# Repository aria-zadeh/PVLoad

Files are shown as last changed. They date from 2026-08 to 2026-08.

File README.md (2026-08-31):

# PVLoad

Automated I-V curve measurement for photovoltaic cells. A programmable resistive load steps through
769 load states while two bench multimeters record voltage and current at each one.

Hardware is a 2-layer PCB carrying two SPI digital potentiometers and three reed relays. Control is
MATLAB, over an Arduino Uno.

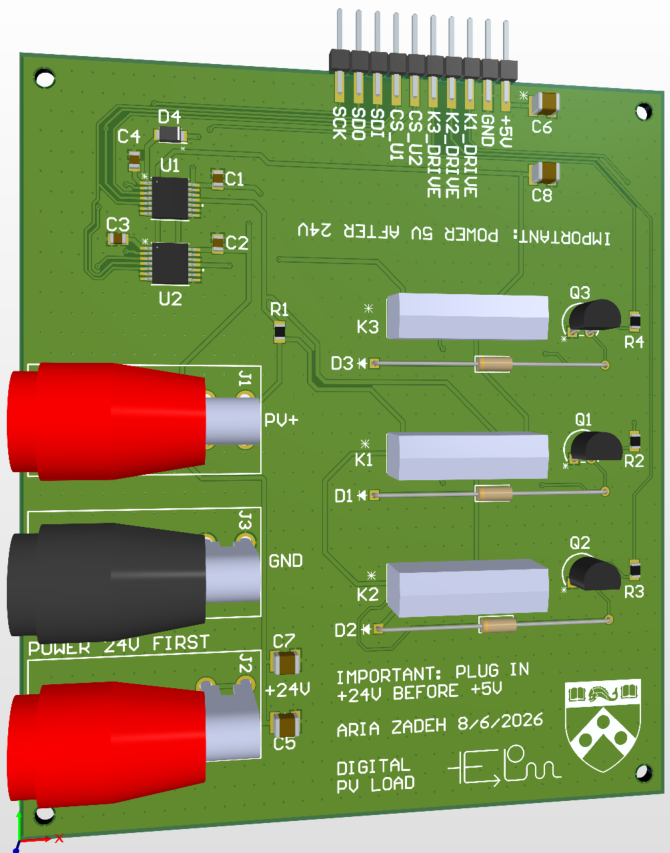
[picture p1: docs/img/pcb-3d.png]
PCB 3D render


## Overview

A cell's operating point depends on its load, so characterizing one means sweeping the load and
recording voltage and current at each step. This board replaces a manually adjusted resistor with
two MCP41HV51 digital potentiometers in series and three reed relays, giving 769 distinct load
states from 0.150 Ω to 470 kΩ under software control.

Relays reconfigure the topology to reach the ends of the curve, which the potentiometers cannot:

| Mode | Relay action | Region |
|---|---|---|
| `SHORT` | Bypass the whole load | Short-circuit current |
| `LOW` | Bypass the second potentiometer | ~155 Ω to 5.2 kΩ |
| `FULL` | Both potentiometers in series | ~310 Ω to 10.3 kΩ |
| `OPEN` | 470 kΩ in series | Open-circuit voltage |

`LOW` and `FULL` start from one and two wiper resistances respectively. The offset is not an integer
number of steps, so the two ladders interleave and resolve finer than the 19.6 Ω step size.

An I-V curve is only defined at a stated illumination, but the illumination is set by hand and the
software does not touch it. One run of the sweep is one curve at whatever light the bench is under;
a family of curves is several runs, told apart by `RUN_TAG`.

The board contains no measurement circuitry. Voltage and current come from two bench multimeters
addressed over VISA: a Keithley 196 and an Agilent 34401A.

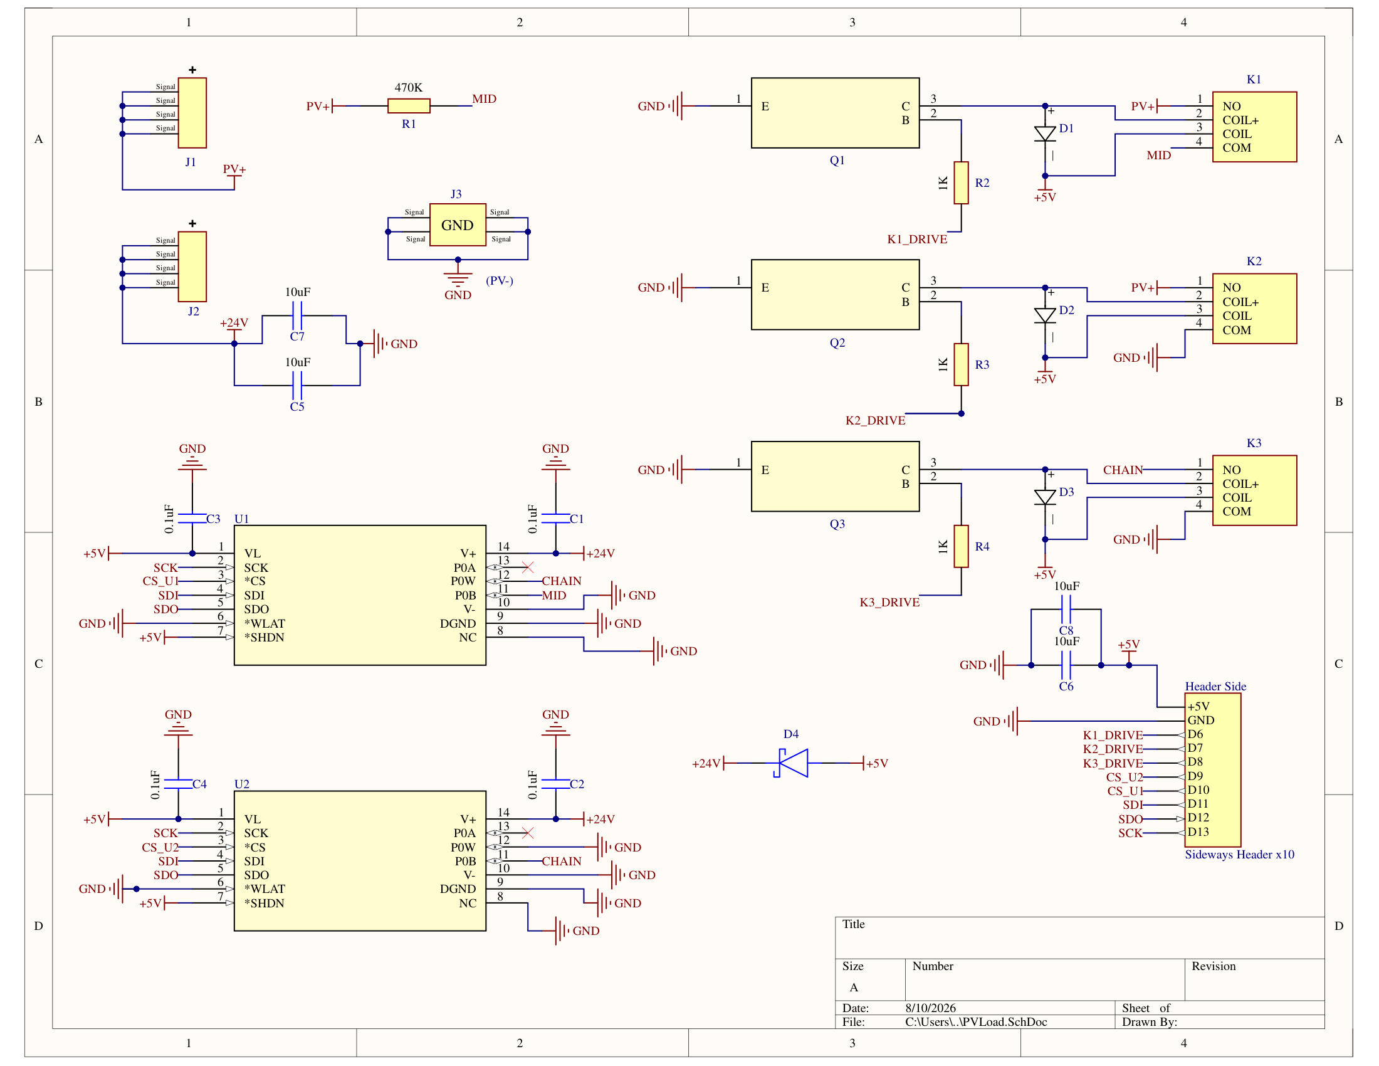
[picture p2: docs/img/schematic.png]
Schematic


## Specifications

| Parameter | Value |
|---|---|
| Load range, both potentiometers | ~310 Ω to 10.3 kΩ |
| Load range, one potentiometer bypassed | ~155 Ω to 5.2 kΩ |
| Step size | ~19.6 Ω |
| Load states per sweep | 769 |
| Short-circuit path | 0.150 Ω relay contact |
| Open-circuit path | 470 kΩ |
| Cell under test | ≤9 V open circuit, ≤16 mA short circuit |
| Illumination | Set by hand, not by this software |
| Control | SPI from an Arduino Uno, driven from MATLAB |
| Supplies | 24 V bench supply (analog), 5 V from the Arduino (logic) |
| Board | 2-layer, hand-assembled |

## Design notes

**Two potentiometers.** A single MCP41HV51-502 is 5 kΩ end to end. Two in series reach 10 kΩ and
produce the interleaved ladders described above.

**High-voltage potentiometer.** The MCP41HV51 separates its resistor-network supply from its logic
supply, so the network runs at 24 V while logic runs at 5 V. A cell reaching 9 V would clip a
part powered from the logic rail alone. This is why the board takes two supplies and why power
sequencing matters.

**Reed relays.** At 16 mA, contacts operate in dry-circuit conditions where silver-alloy power
contacts can develop surface films and read as intermittent opens. A sealed reed capsule avoids
this and holds contact resistance to 0.150 Ω, which sets the short-circuit endpoint. Coils draw
10 mA each and run from the Arduino's 5 V pin.

**Relay topology.** Every relay is wired in parallel with an element, never in series, since a
series relay could only break the loop. The open-circuit end is therefore a 470 kΩ resistor that K1
shorts out for the rest of the sweep, passing ~19 µA at 9 V.

**Coil drivers.** Each coil is switched by a 2N3904 low-side NPN through a 1 kΩ base resistor, with
a 1N4148 flyback diode across the coil. The relay has no internal diode.

**No on-board ADC.** An integrated converter would require calibration against a bench meter, so
the meters are used directly.

**Two meters.** Current is measured in series and voltage in parallel; one instrument cannot do
both simultaneously. Both are triggered before either reply is read, so their conversions overlap
and the readings describe the same instant. They need not be the same model, and on this bench they
are not: the voltmeter and the ammeter carry separate command profiles.

## Repository layout

```
docs/
  HARDWARE.md      Topology, pin map, SPI protocol, BOM
  DECISIONS.md     Design rationale and open questions
  BRINGUP.md       What has been measured on the assembled board
  METERS.md        The two meters, their dialects and status words
  TROUBLESHOOTING.md  Finding a fault with a handheld meter
  PVLoad_BenchCard.pdf   One-page printable bench reference
  benchcard.html   Source for the bench card
  img/             Schematic and PCB renders
hardware/
  altium/          Altium project, footprint and symbol libraries, STEP model
  gerbers/         Gerber X2 and NC drill files
  bom.pdf          Bill of materials
matlab/
  PVLoad_Main.m    Sweep controller and meter drivers
  test_arduino.m   Pin-by-pin bench test of the Arduino alone
data/
  sweep_data/      CSV output
figures/
  family_*.png     I-V and P-V across the laser drive levels, raw and fitted
```

[`docs/HARDWARE.md`](docs/HARDWARE.md) is the hardware reference: node-by-node topology, Arduino pin
map, SPI command format, initialization requirements, timing, and BOM with part selection reasoning.
[`docs/DECISIONS.md`](docs/DECISIONS.md) covers software design rationale and unresolved items.

## Requirements

| Component | Requires |
|---|---|
| Board | MATLAB R2019a+, MATLAB Support Package for Arduino Hardware, Arduino Uno, 24 V bench supply |
| Meters | A Keithley 196 and an Agilent 34401A, in either role. USB-GPIB adapter, Instrument Control Toolbox, vendor VISA runtime |
| Illumination | Whatever lights the cell. Set and recorded by hand |

No firmware to compile. The support package ships its own, and SPI transactions are issued from the
host over USB.

Instrument Control Toolbox does not include a VISA implementation. Install NI-VISA or Keysight IO
Libraries separately, matching the vendor to your GPIB adapter. Without one, `visadevlist` reports
`Unable to find VISA installations`; with one and no instruments attached it reports `Unable to
find any VISA resources`.

`DMM_V_MODEL`, `DMM_I_MODEL`, and `DMM_R_MODEL` select the instrument for each meter, from `"196"`
and `"34401A"`. The model is named per meter rather than once for the bench, so the voltmeter and
the ammeter can be different instruments, and here they are. One profile per model at the top of
Part 2 holds what differs: which command selects which function, what ranges exist, and how a
reading is decoded. Each meter carries its own profile from the moment it is opened.

The two speak different languages. On the 196 a command is a letter and a number, several travel in
one string, and nothing takes effect until an `X` arrives. The 34401A is SCPI, so its commands are
words, one per line, and a reading is a bare number with no prefix. Each profile carries a dialect
and the functions that talk to the bus branch on it, so both are in use at once during a sweep.

The 196 profile is read off Keithley 196-901-01 Rev D: functions from §3.9.2, ranges from table 3-9,
the setup string from table 3-8, the 24 ms conversion from table 3-16, and the reading tags from
figure 3-6. The 34401A profile is read off 34401-90004. Both have now been opened, identified and
configured on the bench; neither has been run against a cell. Either way the setup is followed by
the error query, so a command the meter does not know fails at configuration rather than producing a
wrong number. [docs/BRINGUP.md](docs/BRINGUP.md) records what the bench actually said, including the
three faults that took getting there.

The 196 has an IEEE-488 interface and nothing else, so it requires a USB-GPIB adapter. Match the
adapter to the installed VISA: NI-VISA drives National Instruments hardware, Keysight IO Libraries
drive Keysight hardware. The 34401A also has an RS-232 port, which VISA reaches as an `ASRL`
resource; the script sends `SYST:REM` on that transport only, because GPIB addressing does the same
job and the command is not valid there.

On Windows, Keysight VISA can fail inside MATLAB while working in every other program. MATLAB loads
the copy of `MSVCP140.dll` it ships in `bin\win64` in preference to the system copy, and if that copy
is older than the runtime Keysight IO Libraries was built against, the Keysight VISA library fails to
initialise. `instrhwinfo('visa')` then omits `keysight` and `visadevlist` finds nothing.
[docs/TROUBLESHOOTING.md](docs/TROUBLESHOOTING.md) has the diagnosis and the fix.

## Setup

Order matters. The cell is a supply, so it goes in last and comes out first — see
[Safety](#safety).

1. Connect the Arduino to the board through the 1x10 header.
2. Connect the bench supply to J2 (+24 V) and J3 (GND).
3. Connect the cell to J1 (PV+) and J3 (GND), with the ammeter in series on the PV+ lead, and
   keep it dark for now. Current goes into the ammeter's own terminal, `AMPS` on the 196 and the
   fused current terminal on the 34401A, never the volts terminal.
4. Connect the voltmeter across the cell terminals, upstream of the ammeter. Not across J1 and J3 —
   see [Measurement notes](#measurement-notes).
5. Power up 24 V first, then the Arduino.
6. Set `RUN`, the port and address settings, and `RUN_TAG` in Part 1 of `matlab/PVLoad_Main.m`,
   then start it.
7. Illuminate the cell once the script is running and the relays are in a defined state.

Shut down in reverse: darken the cell, then the Arduino's 5 V, then 24 V.

## Usage

`RUN` selects the mode. Each opens only the hardware it needs, so subsystems can be brought up
independently.

| `RUN` | Opens | Purpose |
|---|---|---|
| `"plan"` | nothing | Validate configuration, print time estimate |
| `"board"` | Arduino | Safe state, potentiometer self-test, walk a spread of load states |
| `"ramp"` | Arduino | Climb the resistance range slowly enough to follow on a handheld meter |
| `"wiper"` | Arduino | Park at the state pairs whose difference is one wiper resistance |
| `"verify"` | Arduino | Seven holds that exercise every part of a freshly built board |
| `"ohms"` | Arduino, one meter | Measure every state in the sweep on ohms, write a CSV and save a plot |
| `"meters"` | both sweep meters | Identify, configure, take ten readings |
| `"sweep"` | Arduino, both meters | Full experiment, written to CSV |

`"sweep"` enters the safe state, self-tests both potentiometers over SPI, sizes the ammeter range
once, then steps through every load state:

```
[  42/ 769] LOW    U1= 41  U2=  0  ~   1004.1 ohm   V=  6.21180  I=   9.8340 mA
```

Press Ctrl-C once and wait ~3 seconds to abort. The cleanup handler returns the board to `OPEN` and
closes the meters. Darkening the cell is yours, the same as lighting it was.

`SELF_TEST = false` skips potentiometer readback, allowing the control flow to run on a bare Arduino
with the board disconnected.

## Configuration

`PVLoad_Main.m` is split into two parts. Part 1 holds the settings intended to be changed. Part 2
describes the pin map and the meter command sets, and changes only with the hardware.

| Setting | Description |
|---|---|
| `RUN` | Mode, per the table above |
| `SERIAL_PORT` | Arduino COM port; enumerate with `serialportlist("available")` |
| `DMM_V_ADDRESS`, `DMM_I_ADDRESS` | VISA resource strings; enumerate with `visadevlist` |
| `DMM_R_ADDRESS` | VISA resource string of the single meter `"ohms"` uses; that mode ignores `DMM_ENABLED` |
| `DMM_V_MODEL`, `DMM_I_MODEL`, `DMM_R_MODEL` | `"196"` or `"34401A"` per meter; selects the command profile and range lists. They need not match |
| `DMM_V_RANGE`, `DMM_I_RANGE`, `DMM_R_RANGE` | Fixed meter ranges, or 0 to size from the probe and then follow the reading |
| `CODE_STEP` | States visited, `767/step + 2`. 1 gives 769 and about six minutes, 16 gives 50 and about half a minute |
| `POINT_BUDGET` | The most one state may cost end to end. The hold is what is left after the conversion and the board |
| `DMM_ENABLED` | Whether both sweep meters are attached |
| `ISC_FULL`, `VOC_FULL` | Zero, the normal setting, means the sweep measures the cell itself before it starts and sizes the meters from that. A number pins the range instead, for a family of runs at different light |
| `RAMP_STEPS`, `RAMP_DWELL` | States visited by `"ramp"` and how long each state is held |
| `DMM_NPLC`, `DMM_LINE_HZ` | Integration time in power line cycles, and the mains frequency that turns it into seconds. 34401A only |
| `WIPER_CODES` | Codes `"wiper"` compares at |
| `OHMS_SETTLE` | Per-state hold in `"ohms"` before the reading is triggered |
| `SETTLE_TIME` | Per-state hold when no meters are attached |
| `WRITE_CSV`, `OUT_DIR`, `RUN_TAG` | Output. `RUN_TAG` is the only record of the illumination |

The two meters are not the same speed. The 196 has a resolution setting rather than an integration
time; its profile asks for 5.5 digits, which is one line cycle of integration and 24 ms from trigger
to reading-ready. The 34401A integrates for `DMM_NPLC` power line cycles, doubled when
`DMM_ZERO_CORRECT` is set because autozero takes a zero reading between measurements: about 390 ms
at the default 10 NPLC. Both are triggered before either reply is read, so a point costs the slower
of the two rather than their sum, and a 769-state sweep takes about six minutes. `RUN = "plan"`
prints the estimate for a given configuration.

### Checking the load with a handheld meter

`RUN = "ramp"` needs no cell and no bench meters. Bring up 24 V, then the Arduino,
clip a handheld meter across J1 and J3 in ohms, and run it. The board climbs from the `SHORT` relay
contact to the 470 kΩ `OPEN` path in `RAMP_STEPS` stages, holding each for `RAMP_DWELL` seconds so
an autoranging meter has time to settle.

The printed ohms come from the resistance model, not from the board. `R_WIPER` is a worst-case
bound rather than a measurement and `R_AB` is ±20%, so expect the meter to disagree.

`RUN = "wiper"` turns that disagreement into a number. Probe, jack and trace resistance is common
to every reading a handheld takes, so it is removed by subtracting two readings rather than by
trusting either one. Writing `s` for the ladder step, and noting that a `FULL` state at code sum
`n` puts `U1` at `n` and `U2` at zero:

```
SHORT   = K2
LOW(n)  = K1 + Rw1 + n·s + K3
FULL(n) = K1 + Rw1 + n·s + Rw2
```

`LOW(0) − SHORT` is `Rw1` and `FULL(n) − LOW(n)` is `Rw2`, each to within a 0.150 Ω reed contact.
Neither difference contains the leads, the jacks or K1. `Rw2` is a switch rather than a resistor,
so the same value should come back at every code in `WIPER_CODES`; one that tracks the code is
`R_AB` being wrong instead.

### Measuring the load with one meter

`RUN = "ohms"` is `"ramp"` with the copying down done by an instrument. It needs the Arduino and a
single meter on ohms across J1 and J3, with no cell and no second meter, so
`DMM_ENABLED` stays out of it and `DMM_R_ADDRESS` says which meter to open. Bring up 24 V before the
Arduino as usual: the potentiometer resistor networks run from that rail, and a board without it
reads as series resistance rather than as a ladder. Every one of the 769 states is visited once,
held for `OHMS_SETTLE`, and read.

The output is two files under `OUT_DIR`, sharing one timestamp: `pvload_<stamp>_ohms.csv` with a row
per state, and `pvload_<stamp>_ohms.png` plotting measured resistance against the model on log axes,
with the ratio of the two below it. A ratio of 1 is agreement.

Neither meter reaches the bottom of the sweep: the lowest ohms range is 300 Ω on the 196 and 100 Ω
on the 34401A, against a 0.150 Ω `SHORT` contact. `DMM_R_RANGE` therefore defaults to the instrument's own
autorange, and the low end is measured on the coarsest part of the most sensitive range. Points the
meter returns as zero or negative stay in the CSV and are counted on the console rather than plotted.
A reading carries the leads, the jacks and the traces exactly as a handheld does, so a constant few
ohms across every point is the wiring.

`R_WIPER` is 155 Ω per device, measured with `RUN = "verify"` on the assembled board and recorded
in [docs/BRINGUP.md](docs/BRINGUP.md). `CELL_SETTLE` is still a placeholder at zero, and it is the
settle-model term that matters most at high resistance. Measure and replace it.

## Output

`"sweep"` writes one timestamped CSV to `data/sweep_data/`, `pvload_<stamp>.csv`, with a row per
point: `timestamp`, `state_index`, `mode`, `u1_code`, `u2_code`, `r_nominal_ohm`, `voltage_v`,
`current_a`, `resistance_ohm`, `power_w`, `settle_s`.

`resistance_ohm` and `power_w` are derived from measured voltage and current. `r_nominal_ohm` is the
model estimate used to order the sweep and is not a measurement.

Nothing in the file records the illumination, because nothing in the script knows it. Set `RUN_TAG`
before the run; it goes into the file name and is what tells two runs at different light apart.

Rows are appended in blocks of 64 states, so an aborted run retains everything up to the last block
boundary. The timestamp is what stops a second run overwriting the first.

## Measurement notes

Neither instrument here is an electrometer. Both are 6.5 digit DMMs, and both of the arguments
below follow from that.

**Burden voltage.** Connect the voltmeter across the cell terminals, upstream of the ammeter, rather
than across J1 and J3. A voltmeter downstream of the ammeter reads low by the ammeter's burden drop,
and both of these meters read current across a shunt. On the 34401A the shunt is 5 Ω for the 10 mA
and 100 mA ranges, so a 16 mA cell on the 100 mA range costs 80 mV. That is large enough to change
the shape of the curve, not just its offset.

**Input impedance, and which meter to put on volts.** Both meters present megohms rather than
hundreds of teraohms, and against the 470 kΩ `OPEN` path that is a divider rather than a rounding
error: a 10 MΩ input reads Voc about 4.5% low.

The 34401A can be told otherwise. `INP:IMP:AUTO ON` raises its input past 10 GΩ, and the script
sends that command to whichever meter is the voltmeter. It only applies on the 100 mV, 1 V, and
10 V ranges, so a `VOC_FULL` that pushes the meter onto 100 V puts the divider back. The setting is
volatile and `CONFigure` clears it, which is why it is sent after the range on every configuration.

The 196 has no equivalent command. Its 30 V range, where a 9 V Voc lands, is 10 MΩ.

So put the **34401A on volts and the 196 on amps**. On current the two are close enough not to
matter; on voltage they are not. Nothing in the configuration warns about this, because nothing in
the configuration knows the source impedance of the cell.

**Current range.** A ~16 mA cell lands on the 196's 30 mA range and the 34401A's 100 mA range. The
range starts where the probe put it and then follows the reading, widening at 90 % of range or on
an overflow and narrowing under 8 %. A cell whose illumination drifts costs a range change rather
than the run. An `ISC_FULL` above the meter's top range is
refused at configuration time; one far below its lowest range is a warning, not an error.

**Isc.** The burden drop and the 0.150 Ω relay contact put the `SHORT` state at millivolts rather
than at 0 V. Voltage is measured at every point, so `SHORT` is the lowest-voltage point on the curve
rather than a point defined to be at zero. Isc is obtained by extrapolating to V = 0.

Instrument commands are collected in one profile per model in Part 2, selected per meter by
`DMM_V_MODEL`, `DMM_I_MODEL`, and `DMM_R_MODEL`. Two dialects are supported: Keithley's own
device-dependent command language, which does not port beyond that family, and SCPI.

## Safety

- 24 V must come up before 5 V, and 5 V must come down first. D4, a Schottky from +5 V to +24 V,
  clamps the rails if the sequence is wrong, but it does not make the board usable on 5 V alone:
  V+ then sits about 0.35 V below VL, far below the 10 V the resistor network needs. There is no
  overvoltage protection, and a bench supply connected backwards gives the Arduino's 5 V rail a
  current path through D4.
- **The cell is a supply, so it belongs in the sequence too: illuminate it last, darken it first.**
  PV+ reaches U1's P0B, through R1 normally and directly through K1's contacts once K1 is energized.
  The datasheet limits those pins to `V+ + 0.3 V`, so a lit cell on an unpowered board is roughly
  8.7 V past absolute maximum. With all relays released, R1 holds that to ~19 µA against a ±20 mA
  clamp rating, which is harmless. But if 24 V drops out while 5 V is still up and K1 is closed, R1
  is shorted and the cell's full ~16 mA goes into the clamp — 80% of the absolute maximum, and the
  case that destroys a chip. D4 does not protect this path; it sits between the rails. Blocking the
  light is equivalent to unplugging and easier on the jacks. Since the illumination is set by hand,
  this sequence is entirely yours to get right; nothing in the software can enforce it.
  `docs/HARDWARE.md` §7 has the ratings.
- Never close the short-circuit relay during an open-circuit reading. A 0.150 Ω contact in parallel
  with 470 kΩ collapses the reading to roughly 0 V.
- Do not calculate resistance from the wiper code. The potentiometers carry ±20% tolerance and
  wiper resistance at a 24 V span is not characterized. Work from measured voltage and current.

## Testing without the board

`matlab/test_arduino.m` verifies that every pin the design uses can drive and read, using only the
Arduino, a USB cable, a multimeter, and jumper wires. It includes an SPI loopback test.

## License

MIT. See [LICENSE](LICENSE).

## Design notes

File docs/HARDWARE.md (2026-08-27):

# PVLoad-R1 Hardware Specification

Digitally controlled programmable resistive load for photovoltaic cell I-V characterization.
This document is the complete reference needed to write control software for the board.
It describes what the hardware is and how to drive it. It does not cover PCB layout or fabrication.

---

## 1. What the board does

Two high-voltage SPI digital potentiometers are wired in series to form a two-terminal load.
Three reed relays bypass parts of that load to extend the reachable range past what the
potentiometers alone can produce. An Arduino Uno sets the wiper codes and relay states.

The board is placed in a single series loop with a PV cell. Sweeping the load and recording
voltage and current at each step traces the cell's I-V curve, from which the maximum power
point, fill factor, and matched load resistance are computed.

**The board contains no measurement circuitry.** Voltage and current are read by two external bench
multimeters addressed over VISA, a Keithley 196 and an Agilent 34401A. Software sets the load state,
reads both meters at each point, and writes the results to CSV.

### Design targets

| Parameter | Value |
|---|---|
| Device under test | PV cell, up to ~9 V open circuit, ~16 mA short circuit |
| Load range, both pots in circuit | ~400 Ω to 10 kΩ |
| Load range, DigiPot 2 bypassed | ~155 Ω to 5.2 kΩ |
| Step resolution | ~19.6 Ω per code (5000 Ω / 255) |
| Short circuit path | Relay contact, 0.150 Ω max |
| Open circuit path | 470 kΩ, ~19 µA at 9 V |
| Control interface | SPI from Arduino Uno, driven from the host PC |
| Analog supply | 24 V from bench supply |
| Logic supply | 5 V from the Arduino |

---

## 2. Topology

Five nodes carry the analog current. Every relay bridges exactly two of them.

```
PV+ ── R1 (470k) ── MID ── U1 (P0B→P0W) ── CHAIN ── U2 (P0B→P0W) ── RETURN ── GND
       [K1 bypasses R1]                    [K3 bypasses U2]
       [K2 bridges PV+ directly to RETURN, shorting the whole load]
```

| Node | Connections |
|---|---|
| PV+ | J1 (cell positive), R1 one end, K1 contact A, K2 contact A |
| MID | R1 other end, K1 contact B, U1 P0B |
| CHAIN | U1 P0W, U2 P0B, K3 contact A |
| RETURN | U2 P0W, K2 contact B, K3 contact B, GND |
| GND | J3 (shared return for cell and bench supply), Arduino GND, chip grounds |

Relays are always wired in parallel with an element, never in series. A relay in series could
only open the loop; in parallel it offers current a near-zero-ohm alternate path.

Both DigiPots are used as rheostats (two terminal). Current enters at P0B and leaves at P0W.
P0A is left unconnected on both chips.

---

## 3. Operating modes

| Mode | D6 (K1) | D7 (K2) | D8 (K3) | Load seen by the cell |
|---|---|---|---|---|
| `SHORT` | HIGH | HIGH | LOW | Near zero ohms. Yields Isc. |
| `LOW` | HIGH | LOW | HIGH | DigiPot 2 shorted. ~155 Ω to ~5.2 kΩ. |
| `FULL` | HIGH | LOW | LOW | Both pots in series, 470 kΩ shorted. ~310 Ω to ~10.3 kΩ. |
| `OPEN` | LOW | LOW | LOW | 470 kΩ in series. Yields Voc. |

K3 is a don't-care in `SHORT` because K2 already bypasses everything downstream of PV+. Drive it LOW
anyway so the state is fully defined.

**Note the inverted sense of D6.** K1 is normally open and sits across the 470 kΩ, so it must be
energized to hide that resistor during a sweep, and de-energized only for the Voc reading. Side
effect: if the Arduino resets or loses power, all three relays release and the cell settles near
open circuit, which is the safe state.

**Never close K2 during a Voc reading.** A 0.150 Ω contact in parallel with 470 kΩ collapses the
measurement to roughly 0 V.

---

## 4. Arduino pin map

Arduino Uno mounts off-board and connects through a 1x10 header.

| Header pin | Arduino pin | Function |
|---|---|---|
| 1 | 5 V | Logic supply and relay coil supply (~30 mA of coils max) |
| 2 | GND | Common reference |
| 3 | D6 | K1 drive, open circuit relay |
| 4 | D7 | K2 drive, short circuit relay |
| 5 | D8 | K3 drive, DigiPot 2 bypass |
| 6 | D9 | U2 CS# (DigiPot 2) |
| 7 | D10 | U1 CS# (DigiPot 1) |
| 8 | D11 | SPI MOSI, to SDI on both chips |
| 9 | D12 | SPI MISO, from SDO on both chips |
| 10 | D13 | SPI SCK, to both chips |

Relay drive is active high: pin HIGH turns on an NPN low-side switch through a 1 kΩ base
resistor, which energizes the coil.

D2 to D5 and all analog inputs are unused and not brought to the header.

---

## 5. SPI protocol

The device is Microchip MCP41HV51 (8-bit, 5 kΩ, SPI). Two chips, each with its own chip select.
The part does not support daisy chaining, so they are addressed independently.

- Chip select is active low.
- SPI mode 0,0 (also supports 1,1). Clock up to 10 MHz. MSB first.
- Assert CS# low, transfer the bytes, raise CS# high. Never leave both CS# low at once.

### Command format

Each command byte is `[4-bit address][2-bit command][2 data bits]`. For an 8-bit device the two
data bits in the command byte are zero and the data rides entirely in the second byte.

Volatile Wiper 0 register, address `0000`:

| Operation | Command byte | Bytes | Notes |
|---|---|---|---|
| Write wiper | `0x00` | 2 | Second byte is the 8-bit wiper code, 0 to 255 |
| Increment | `0x04` | 1 | |
| Decrement | `0x08` | 1 | |
| Read wiper | `0x0C` | 2 | Second byte clocked out on SDO |

TCON register is address `0100`, so its command byte for a write is `0x40`.

The sweep only needs the write command. Verify increment/decrement byte counts against the
datasheet if you use them.

### Resistance model

```
R_BW = R_ZS + n * (R_AB / 255)
```

where `n` is the 8-bit wiper code and `R_ZS` is the zero-scale (wiper) resistance that remains at
code 0. The denominator is 255 because an 8-bit ladder has 255 physical step resistors and 256
tap points.

**Do not compute resistance from the tap code in analysis.** R_AB tolerance is ±20% and wiper
resistance at a 24 V span is not characterized by the datasheet. Measured at 155 Ω per device on
the assembled board.
The code is a repeatable setting, not a known resistance. Always work from measured V and I.

---

## 6. Initialization requirements

Every script must do all of the following before taking any reading:

1. **Set all three relay pins to a defined output state.** On reset the Arduino leaves pins as
   high-impedance inputs, which releases all relays and puts the board in `OPEN`. That is safe,
   but it should be entered deliberately.
2. **Write a known wiper code to both chips.** If V+ comes up before VL, the wiper is forced to
   mid-scale rather than taking the register value. Since the bench supply and the Arduino power
   up independently, the reset state cannot be assumed.
3. **Re-write TCON if a non-default terminal configuration is needed.** TCON loads with all
   terminals connected after a reset. The default is correct for this board, so this is usually a
   no-op.

### Settling time

Relays specify 1.0 ms maximum operate and release. The DigiPot settles in about 1 µs. Use a
conservative 10 ms delay after any state change before reading.

---

## 7. Power and safety rules for software

| Rail | Source | Loads |
|---|---|---|
| +5 V | Arduino 5 V pin | VL and SHDN# on both chips, all three relay coils, flyback diode cathodes |
| +24 V | Bench supply | V+ on both chips |
| GND | Common | Arduino GND, cell negative, supply return, DGND/V-/NC/WLAT# on both chips |

Two supplies exist because the chip has two power domains. Logic (VL to DGND) must sit between
2.7 V and 5.5 V. The resistor network terminals must stay between V- and V+, and the cell reaches
about 9 V, above what a 5 V rail could contain.

**Power sequencing is an operator procedure, not enforced by the board.**

```
Up:    24 V  ->  5 V  ->  run the script  ->  illuminate the cell
Down:  darken the cell  ->  5 V  ->  24 V
```

A Schottky diode (D4) across the rails clamps a wrong rail order, but the board is non-functional on
5 V alone, has no overvoltage protection, and has a reverse-polarity current path if the bench
supply is connected backwards.

### The cell is part of the sequence

The cell is a supply too, and it lands on U1's P0B, through R1 always and directly through K1's
contacts whenever K1 is energized. The datasheet limits those pins to
`-0.3 V to V+ + 0.3 V` with respect to V-, so with the board unpowered and V+ at 0 V, an
illuminated cell at 9 V sits about 8.7 V outside absolute maximum and conducts into the internal
clamp. Two cases, three orders of magnitude apart:

| State | What limits the current | Severity |
|---|---|---|
| Board unpowered, cell lit | All relays released, so R1 (470 kΩ) is in circuit. ~19 µA into the clamp. | Outside abs max on paper. Against a ±20 mA clamp rating that is 1000x margin, so harmless. It does pull V+ up through the die. |
| 5 V up, K1 energized, 24 V absent or dropped out | Nothing. K1 shorts R1, so the only limit is the cell's Isc, ~16 mA, into the clamp with V+ at 0 V. | 80% of the ±20 mA absolute maximum clamp current, which is a damage threshold rather than an operating rating. This is the case that destroys a chip. |

Losing 24 V while 5 V is still up and K1 is closed is the failure window, which is why the cell is
darkened before either rail comes down.

**D4 does not protect against this.** It sits between the two rails and does nothing for the PV
input path.

The jacks do not have to be unplugged each cycle. A dark cell sources almost nothing, so blocking
the light is equivalent and spares the connectors. To connect a lit cell to a live board, put the
board in `OPEN` first so R1 is in circuit.

Relevant absolute maximum ratings, MCP41HVX1 datasheet DS20005207:

| Rating | Value |
|---|---|
| Voltage on PxA, PxW, PxB with respect to V- | -0.3 V to V+ + 0.3 V |
| Input clamp current, I_IK | ±20 mA |
| Continuous current into PxA, PxW, PxB (R_AB = 5 kΩ) | ±25 mA |

Software should assume nothing about the power state and always initialize as in section 6.

---

## 8. Measurement procedure

At every sweep point the operation is two-part: software sets the state, the operator reads the
meters.

1. Set the mode (relay pins) and the wiper codes over SPI.
2. Wait 10 ms for settling.
3. Read voltage and current from the external meters, record against the tap code.

Current is measured by breaking the PV+ lead outside the board and putting the ammeter in series
ahead of J1. Voltage is measured across the cell itself, on the cell side of the ammeter, **not**
across J1 and J3: a voltmeter placed at the jacks sits downstream of the ammeter and reads low by
the burden drop. See the note at the end of this section.

Two meters are needed to capture the same operating point. With one meter each point must be
visited twice, which assumes the light has not changed between readings.

### Sweep order

Sweep from lowest resistance to highest, so the cell is walked monotonically from short circuit to
open circuit rather than jumping between the two endpoints:

1. `SHORT`, one state. Isc endpoint.
2. `LOW`, one state per U1 code, 0 to 255. 256 states.
3. `FULL`, one state per *combined* code, 0 to 510, split across the two chips. 511 states.
4. `OPEN`, one state. Voc endpoint.

769 states, each a distinct circuit. In `FULL` only the sum of the two codes affects resistance, so
`(10, 20)` and `(15, 15)` are the same circuit and only one of them is visited.

Keeping `LOW` as well as `FULL` is what makes the sweep finer than one wiper step. `LOW` starts at
one wiper resistance and `FULL` at two, both climbing in the same ~19.6 Ω steps. The offset between
them is not a whole number of steps, so `FULL`'s points land between `LOW`'s rather than on top of
them, and the pair reaches resistances neither reaches alone.

### Analysis

Maximum power point is the maximum of V x I over all sampled points. Matched load resistance is
V/I at that point. It cannot be estimated as Voc/Isc, because both endpoints deliver zero power.
The maximum sits at the knee, typically 70% to 80% of Voc for a silicon cell.

### Log format

One row per sampled point:

| Column | Content |
|---|---|
| `u1_code` | Tap code written to DigiPot 1 |
| `u2_code` | Tap code written to DigiPot 2 |
| `mode` | `SHORT`, `LOW`, `FULL`, or `OPEN` |
| `voltage_v` | Measured, external meter |
| `current_a` | Measured, external meter |
| `timestamp` | ISO 8601 |

Illumination conditions must be recorded once per sweep. An I-V curve is only meaningful at a
stated illumination, and the control software neither sets it nor knows it: the lamp is an operator
matter, and one run of the sweep is one curve at whatever light the bench is under. Nothing in the
log records that, so `RUN_TAG` goes into the file name and is where the illumination has to be
written down.

Two notes on putting bench meters in this circuit. Neither is a board problem, and neither needs a
board change.

**Put the voltmeter on the cell side of the ammeter.** Any ammeter costs the loop some voltage, and
both meters here drop it across an internal shunt: 5 ohm on the 34401A's 10 mA and 100 mA ranges,
which is 80 mV at 16 mA. With the ammeter ahead of J1, a voltmeter across J1 and J3 sits
*downstream* of that drop and reads short of the cell's terminal voltage by it. Clipping the
voltmeter directly to the cell leads, upstream of the ammeter, removes it. At 80 mV against a 9 V
Voc this is not a rounding error, so it is worth getting right rather than merely tidy.

**The burden shifts where `SHORT` lands, and that is all.** With tens of millivolts inline the cell
sits above the 0.150 ohm contact alone at the `SHORT` state. That does not corrupt the measurement,
because voltage is measured at every point rather than assumed: `SHORT` is simply the lowest-voltage
point on the curve, not a point defined to be at zero. Isc is the V -> 0 intercept extrapolated from
the lowest few points, which is how it should be extracted in any case.

**Put the 34401A on volts.** Neither meter is an electrometer, so at the `OPEN` state each is a
finite impedance across a 470 kohm source. A 10 Mohm input reads Voc about 4.5% low. The 34401A can
be told to raise its input above 10 Gohm on its 100 mV, 1 V and 10 V ranges, and the software sends
that command to whichever meter is the voltmeter; the 196 has no such command and its 30 V range,
where a 9 V cell lands, is 10 Mohm. On current the two are close enough that the choice does not
matter. This is a wiring decision, not a board one, and nothing in the software can detect it.

The current range is not much of a choice either. A ~16 mA cell lands on the 196's 30 mA range and
the 34401A's 100 mA range. A cell that outruns the top range needs an external shunt or weaker
light; the software refuses it rather than reading a saturated range.

---

## 9. Bill of materials

| Ref | Qty | Part | Description |
|---|---|---|---|
| U1, U2 | 2 | Microchip MCP41HV51-502E/ST | 5 kΩ 8-bit SPI digital potentiometer, TSSOP-14 |
| K1, K2, K3 | 3 | Littelfuse HE3621A0540 | Reed relay, SPST-NO, 5 V / 500 Ω coil, shielded, 4-pin SIL |
| Q1, Q2, Q3 | 3 | onsemi 2N3904BU | NPN transistor, TO-92, relay coil driver |
| D1, D2, D3 | 3 | onsemi 1N4148 | Switching diode, DO-35, coil flyback clamp |
| D4 | 1 | Diodes Inc. 1N5819HW-7-F | Schottky, SOD-123, rail sequencing protection. Anode +5 V, cathode +24 V. |
| R1 | 1 | Yageo RC0805FR-07470KL | 470 kΩ, 1%, 0805. Open circuit path. |
| R2, R3, R4 | 3 | Yageo RC0805FR-071KL | 1 kΩ, 1%, 0805. Transistor base current limit. |
| C1 to C4 | 4 | Samsung CL21B104KBCNNNC | 0.1 µF, 50 V, X7R, 0805. One per chip power pin. |
| C5 | 1 | Samsung CL32B106KBJNNNE | 10 µF, 50 V, X7R, 1210. Bulk on +24 V, non-polarized. |
| C6 | 1 | Samsung CL32B106KBJNNNE | 10 µF, 50 V, X7R, 1210. Bulk on +5 V. |
| C7, C8 | 0 | Samsung CL32B106KBJNNNE | Not fitted. Optional footprints paralleling C5 and C6. |
| J1, J2 | 2 | Cal Test CT3151-2 (red) | 4 mm banana jack. J1 = PV+, J2 = +24 V. |
| J3 | 1 | Cal Test CT3151-0 (black) | 4 mm banana jack. GND, shared return. |
| MCU1 | 1 | Sullins PRPC010SAAN-RC | 1x10 vertical header, 2.54 mm, off-board Arduino Uno |

Selection notes that affect behavior:

- **MCP41HV51-502E/ST**: 502 = 5 kΩ. Two in series give the 10 kΩ ceiling. Max wiper current
  25 mA against 16 mA here. R_AB tolerance ±20%, so the pair is nominally 10 kΩ but legitimately
  8 kΩ to 12 kΩ.
- **HE3621A0540**: the -40 suffix means external shield and no internal coil diode, which is why
  D1 to D3 are fitted externally. The part is obsolete and will not be restocked.
- **Reed contacts over armature**: 16 mA is dry-circuit territory where a silver-alloy power
  contact can develop a surface film and read as an intermittent open. The reed capsule is
  hermetically sealed. Contact resistance 0.150 Ω max.
- **10 mA coils**: three relays draw about 30 mA total, low enough to run off the Arduino 5 V rail.
- **C5 is Class II ceramic** and loses capacitance under DC bias. A 50 V X7R part at 24 V retains
  roughly half its nominal value. Do not quote 10 µF as the effective value.

---

## 10. Chip pin reference

Both chips are wired identically except for chip select.

| Pin | Connects to | Reason |
|---|---|---|
| NC (8) | GND | Datasheet asks for this pin tied to DGND or VL to reduce noise coupling |
| DGND | GND | Digital ground reference |
| V- | GND | Negative rail of the resistor network |
| P0B | U1: MID. U2: CHAIN | Current enters the ladder here |
| P0W | U1: CHAIN. U2: RETURN | Wiper, current leaves here |
| P0A | Not connected | Only needed in divider mode. Connecting it would create a parallel path. |
| V+ | +24 V | Positive rail of the resistor network |
| SHDN# | +5 V | Held high to keep the part active. Pulling it low ties the wiper to P0B, which silently flattens the sweep while every software check still passes. |
| WLAT# | GND | Held low so wiper writes take effect immediately |
| SDO | D12 | Serial data out |
| SDI | D11 | Serial data in |
| CS# | U1: D10. U2: D9 | Active low chip select |
| SCK | D13 | Serial clock |
| VL | +5 V | Logic supply |

---

## 11. Known limitations affecting software

1. Wiper resistance at a 24 V span is not characterized in the datasheet. The 155 Ω per device
   figure is measured on the assembled board rather than taken from a spec. Re-measure it and
   replace the estimate.
2. No on-board sensing means the measured columns of any log come from an operator or an
   instrument that the control script does not own. Design the logger to accept them after the
   fact rather than assuming it can read them.
3. If a host-side SPI API is used (for example a MATLAB Arduino support package), the exact
   read/write call signature is version dependent. Verify the byte order and transaction framing
   on a scope or logic analyzer before trusting it against live hardware.

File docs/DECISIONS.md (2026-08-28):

# Design Decisions

Rationale for the control software. Hardware rationale is in
[HARDWARE.md](HARDWARE.md).

## The sweep measures the cell before it measures the curve

`ISC_FULL` and `VOC_FULL` existed for one reason: the meters are put on a fixed
range before the first state and something has to size them. That number was an
operator's estimate at an illumination the software cannot see, and when it was
wrong by 250×, as it was on the first sweep with a cell, the ammeter spent the
whole run in the bottom 0.2 % of its range.

The sweep already visits the two states that answer the question. `OPEN` is the
largest voltage of the run and `SHORT` the largest current, and every other
state is one of those two with resistance added, so two readings on autorange
bound the whole sweep. `probeRanges` takes them before the run, sizes both
meters from what it found, and leaves the board back at `OPEN`. Both settings
default to zero, meaning measure it; a number still pins the range, which is
what a family of runs at different light wants.

Autorange is reachable for any function rather than ohms alone, which is what
makes the probe possible. The sweep itself still runs on a settled range,
because a range hunt inside a point spends conversions on the wrong one.

## The meters follow their range, one state at a time

Fixed ranges were chosen because a range change costs a reconfiguration and 769
of them would be absurd. Two runs showed what the fixed choice costs.

On volts it is resolution. A 34401A carries 0.0035 % of reading plus 0.0005 % of
range; at 10 mV on the 10 V range the second term is 50 µV against 0.35 µV from
the first, so the bottom of a ladder crossing three decades is almost entirely
range floor. On amps it is survival: a pinned ammeter cannot follow
illumination that moves, and a range it has run off the top of returns overflow,
which is a NaN, which after five in a row aborts the run.

Both meters share one follower now. It widens at 90 % of range or on overflow
and narrows under 8 %, jumping straight to the range that fits, with the gap
between those thresholds providing hysteresis. Overflow is recovered by
widening and reading again rather than logged as a fault. The command is
`RANGe` alone, never `CONF`, which would reset integration time, autozero and
input impedance to the function's defaults. Range changes turn out to be a
handful per run, not one per point, because the sweep is ordered by resistance
and therefore roughly by voltage.

## A point costs a second, and the budget says so

Run time is a decision. The settle formula is an estimate, and an estimate that
asks for seconds per state is exactly the case where waiting costs most: the
longer the sweep, the further anything drifting has moved by the end of it.

`POINT_BUDGET` is what one state may cost end to end. The hold is whatever is
left of it after the conversion and the board have taken their share, so the
ceiling is on the state rather than on the pause inside it. `CODE_STEP` sets how
many states there are, `767/step + 2`, thinning by wiper code and never by
resistance. 16 gives 50 states and a run of about half a minute.

The cap shortens waiting and nothing else. Conversions run to completion, every
reading is collected, and a point that overruns because a meter re-ranged or an
overflow had to be read twice still finishes and still lands in the CSV.

`BOARD_OVERHEAD` is in the arithmetic because leaving it out is what made the
old estimate lie: seven USB round trips per state for the relays, the wipers and
the readbacks. The sweep now reports what a state actually cost against what it
was told, so a gap that size cannot pass unnoticed again.

## Sweep the combined code, not each pot

The two potentiometers are in series, so only the sum of the two wiper codes
affects resistance. Codes (10,20) and (15,15) produce the same circuit.

An earlier version wrote the same code to both chips. That moved the total two
steps at a time and halved the available resolution. The sweep now walks the
combined code 0 to 510 and splits it across the chips, giving one wiper step
(~19.6 ohm) of resolution across the range.

## Keep both ladders

`LOW` (K3 closed, one pot) starts at one wiper resistance, measured at 155 ohm.
`FULL` (both pots) starts at two. Both climb in ~19.6 ohm steps.

155 / 19.6 = 7.9, so the ladders do not align. The `FULL` rungs fall between the
`LOW` rungs, and 245 `FULL` points land inside the `LOW` range at resistances
neither ladder reaches alone. The margin is not large: the closest rungs sit
about 2 ohm apart, so a wiper resistance nearer a whole number of steps would
cost most of the benefit.

An earlier version deleted that overlap as redundant. The offset depends on wiper
resistance, which the datasheet does not characterise at a 24 V span, so the
duplicates were never confirmed to be duplicates. Resistance is read from the
meters, so extra points cost only run time.

What it buys is smaller than the state count suggests. The extra points do not
sit in the middle of the gaps, they sit next to points that already exist: the
sorted sequence is pairs about 2 ohm apart separated by gaps of about 17.6 ohm.
The number that matters is the largest gap, and it falls from 19.6 ohm to
17.6 ohm. That is 10%, not the factor of two that an evenly interleaved second
ladder would give.

The best case is a wiper resistance near half a step, 9.8 ohm, which splits every
gap in two. 155 ohm is 7.9 steps, close to a whole number, so the two ladders
nearly coincide. Nothing in software changes this: 19.6 ohm is 5 kohm over 255
steps and is fixed by the part. Finer steps need a lower-value pot, which costs
range, or more pots in series, each adding another offset.

## Order by estimate, select by structure

The nominal resistance model sorts the sweep low to high and labels the progress
line. It does not determine membership. Uniqueness is guaranteed structurally:
one state per `LOW` code, one per `FULL` code-sum, one `SHORT`, one `OPEN`. That
holds regardless of the real resistances.

To shorten a sweep, raise `CODE_STEP`. It skips codes deliberately rather than
inferring which are redundant.

## Read the wiper back

The original script was write-only and could not distinguish a working board from
an unplugged one. Every wiper write is now read back over SPI and compared, and
both chips are self-tested across a spread of codes before the sweep starts. This
also detects the mid-scale power-on-reset condition that occurs when 24 V comes
up before 5 V.

Only the second returned byte is decoded. The command-error and high data bits in
the first byte are not, since comparing the code detects every failure those bits
would report.

## Illumination left the software

An earlier version drove a Thorlabs EDFA100P over a serial port, held a measured
current-to-power calibration in Part 1, and repeated the whole sweep at each of
several optical powers. All of it is gone: the driver, the calibration arrays,
the level planning and the per-level CSV.

The lamp is set by hand now, so one run of `"sweep"` is one curve at whatever
light the bench happens to be under. A family of curves is several runs. Nothing
in the script knows the illumination, which means nothing in the output records
it either; `RUN_TAG` goes into the file name and is the only place it lives.

That trade is worth naming. What was lost is that a run is no longer
self-describing, and that a mis-set lamp is now an operator error the software
cannot catch. What was gained is that the one Class 3B interlock in the project
is no longer software's problem, an abort has nothing to shut down but relays,
and roughly 700 lines of protocol parsing that had never been run against the
instrument stopped being a maintenance surface.

`ISC_FULL` and `VOC_FULL` survive, because meter ranges still have to be sized
from something. They are now the operator's estimate at the light they set,
rather than a value at a stated `POWER_FULL`.

## Ctrl-C requires onCleanup, which requires a function

The script previously wrapped the sweep in `try`/`catch` and called
`enterSafeState` from the catch block. That does not protect against Ctrl-C: in
MATLAB an interrupt is not an exception and does not run catch blocks. Only
`onCleanup` fires, and only when the workspace holding it is destroyed, which
does not happen to a script's base workspace.

The worst outcome is now a closed relay rather than a pump left at current, but
the argument survives the amplifier: a `SHORT` relay left closed across a lit
cell is exactly the case the power sequencing rules exist to prevent.
`runExperiment` exists to give the cleanup guard a function workspace.

## Isc from an intercept, not from the SHORT point

An ammeter costs the loop some voltage. Both meters on this bench read current
across a shunt: 5 ohm on the 34401A's 10 mA and 100 mA ranges, which is 80 mV at
16 mA. At `SHORT` the cell therefore sits at tens of millivolts rather than at
the 0.150 ohm relay contact alone.

This does not invalidate the Isc endpoint, because voltage is measured at every
point rather than assumed. `SHORT` is the lowest-voltage point on the curve and
carries its own measured voltage. Isc is obtained by extrapolating to V = 0 from
the lowest points, which is the correct extraction method regardless of series
resistance.

The 1 A range would reduce the shunt to 0.1 ohm and was rejected. Meter error
includes a percent-of-range floor fixed in absolute terms, so reading 16 mA on a
1 A range costs roughly an order of magnitude more than the 100 mA range. The
operating-point offset from the larger shunt is small and correctable; the meter
error is neither.

An external series shunt was considered and dropped. It was only relevant to the
single-meter design, where the voltage and current passes saw different circuits.
Two meters removed the need.

## The script writes the data

The original rule was that the script writes no files. That applied while a human
read the meters: the script changed the load and the readings were recorded
elsewhere.

The script now reads the meters, so it holds data that exists nowhere else.
`"sweep"` writes one CSV, timestamped so a second run cannot land on the first
and the directory sorts chronologically.

One file rather than two. The second file held what was constant across an
illumination level, and there are no levels any more; what was constant across a
run is now either in the file name or nowhere.

Rows are appended in blocks of 64 states rather than at the end. A sweep runs for
minutes, and an abort partway should not discard what it measured. A row at a
time would be correct and far too slow, `writetable` reopening the file on every
call.

`resistance_ohm` and `power_w` are computed from measured voltage and current,
never from the wiper code.

## No prompts, and independent run modes

The sweep free-runs. A keypress-per-point mode was added on the assumption of
manual reading and removed when that assumption changed. Two meters keep it that
way; one meter would require sweeping twice with a rewire between passes.

`RUN` exists because the bench was assembled in stages: Arduino, board, meters. A
script that could only run all of it at once would have been untestable for
months. Each mode opens only what it needs, and `plan` opens nothing, so a
configuration change can be checked with no hardware attached.

## Arduino bench test

`test_arduino.m` validates every pin the design uses with only an Arduino, a
meter and jumper wires. The jumper tests matter more than the voltage tests: a pin
can read 5 V and still fail as an input or fail to clock data. `spi_loopback` is
the only test that exercises the SPI peripheral, which is the hardest subsystem to
debug once two TSSOP packages are soldered down.

## Open questions

- Wiper resistance measured 155 ohm per device on board 2, with the two chips
  agreeing to 1%. `R_WIPER` carries that now. The datasheet does not specify the
  part at a 24 V span; its quoted range is 75 ohm typical to 200 ohm maximum.
- The 200 ohm gap between `SHORT` (0.150 ohm) and the lowest pot setting is a
  hardware floor. No relay or code combination reaches inside it.
- `CELL_SETTLE` is zero and unmeasured. The computed hold currently accounts for
  cable and meter capacitance only, about 1 ms at the 470 kohm `OPEN` point,
  small next to the 10 ms relay floor. Cell junction capacitance is the term
  likely to dominate.
- The `OPEN` point degrades as a Voc measurement under weak light. The 470 kohm
  path draws a fixed 19 uA at 9 V: 0.12% of a 16 mA Isc, and 5% of a 0.4 mA one.
  `reportPlan` warns above 5%, but it is checking `ISC_FULL`, which is an
  estimate typed in by hand rather than anything the software measured.
- The 196 profile is now read off the manual rather than inferred: functions from
  section 3.9.2, ranges from table 3-9, the setup string from table 3-8, the
  24 ms conversion from table 3-16. Two things that inference had wrong were the
  lowest amps range, which is 300 uA rather than 3 mA, and the conversion time,
  which was carrying 350 ms.
- Overlapped reads assume a one-shot 196 holds the talker off until the
  conversion it was just triggered for is finished. If it instead returns the
  previous reading, every point is lagged by one state and the curve is shifted
  rather than wrong-looking. Check it at bring-up by stepping between two widely
  separated load states; `DMM_PARALLEL = false` is the fallback.
- The 34401A profile has now had readings come back from it. `RUN = "meters"`
  identifies it, configures it and takes ten. What that run did not settle is
  whether `FETC?` waits for the conversion `INIT` started rather than returning
  stale data, since with no source every reading is the same number either way.
  That is what the overlapped read depends on and it is still assumed.
- Three faults came out of that bring-up and `docs/BRINGUP.md` records them. The
  one worth carrying forward is not any of the three individually: it is that a
  flush which cleared the output buffer discarded the setup string, so the error
  query came back clean because nothing had reached the meter, and the run
  printed ten plausible readings with the ammeter still in DC volts. The guard
  passed by throwing away the thing it was guarding. Front panels are worth
  looking at.
- The 34401A's volts input is 10 Mohm unless `INP:IMP:AUTO ON` raises it, and
  the manual is explicit that `CONFigure` turns that back off, so it is sent
  after the range on every configuration rather than once. It only reaches the
  100 mV, 1 V, and 10 V ranges. Against the 470 kohm `OPEN` path, 10 Mohm reads
  Voc about 4.5% low, so a `VOC_FULL` above 10 V puts the divider back and
  nothing in the configuration warns about it.
- The 196 has the same divider and no way out of it. Its 30 V range, which is
  where a 9 V Voc lands, is 10 Mohm, and there is no input impedance command to
  raise it. So the 34401A is the better voltmeter and the 196 the better
  ammeter, which is the opposite of the way the two were first wired. The code
  does not enforce that; `DMM_V_MODEL` and `DMM_I_MODEL` describe what is
  physically cabled and are the operator's call.
- The profile is per meter rather than per bench because a lab is stocked with
  what it has. Nothing above the transport is shared between the Keithley
  dialect and SCPI, so the pair travels together: an open port and the profile
  that describes it. That is what lets one sweep trigger a 196 with a bare X and
  a 34401A with INIT in the same pass.

## Procedure requirements

Not open questions, but constraints on how the bench is wired:

- The voltmeter connects on the cell side of the ammeter. Downstream of the
  ammeter it reads low by the burden drop, about 80 mV at 16 mA through the
  5 ohm shunt either of these meters uses on its low current ranges.
- 24 V comes up before 5 V, and 5 V comes down first.

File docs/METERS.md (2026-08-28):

# Meters

Two instruments on one GPIB bus, and they speak different languages. This is
what the software knows about each and why. Bring-up history is in
[BRINGUP.md](BRINGUP.md); faults and their symptoms are in
[TROUBLESHOOTING.md](TROUBLESHOOTING.md).

## The pair

A Keithley 196 and an Agilent 34401A. `DMM_V_MODEL`, `DMM_I_MODEL` and
`DMM_R_MODEL` pick the profile per meter and need not match; the bench runs the
34401A on volts and the 196 on amps.

A meter is an open port bundled with its profile, built by `meterSpec` and
opened by `openMeter`. Every bus function takes that bundle, so nothing below
the configuration block knows which instrument it is holding. Each profile
carries a `Dialect`, and the functions that touch the bus branch on it:
`openMeter`, `identifyMeter`, `configureMeter`, `meterTrigger`, `meterFetch`,
`meterDecode`, and the setup check.

There is no Keithley 617 in this project. An earlier version supported one and
none of it survives.

## Which meter goes where

**The 34401A belongs on volts and the 196 on amps.** `INP:IMP:AUTO ON` raises
the 34401A's input past 10 GΩ, but only on the 100 mV, 1 V and 10 V ranges, and
`scpiConfigure` sends it on the voltmeter alone. The 196 has no equivalent, and
its 30 V range is 10 MΩ. On current the two are close enough that the choice
does not matter.

`DMM_V_MODEL` and `DMM_I_MODEL` describe what is physically cabled. Do not
change them to suit the software.

**Neither meter is an electrometer, and that is the whole measurement story.**
Both read current across a shunt, so an ammeter in series adds burden voltage:
about 9.4 Ω total was measured at the `SHORT` state, leads and jacks included.
Both present megohms on volts, which is why the `OPEN` state is a divider
against R1 rather than an open circuit.

## Keithley 196

On the bus at `GPIB0::1::INSTR`, `U0` answering with the prefix `196`. Front
panel address default is 7.

It **predates SCPI**: a command is a letter and a number, several travel in one
string, and nothing happens until an `X` arrives. No `*IDN?` (use `U0`), no
`*RST`, no `SYST:ERR?` (use `U1`).

The profile is read off manual 196-901-01 Rev D, not inferred:

| | |
|---|---|
| Functions, section 3.9.2 | `F0` volts, `F2` ohms, `F3` DC amps |
| Ranges, table 3-9 | volts 300 mV to 300 V, amps **300 µA** to 3 A, ohms 300 Ω to 300 MΩ, `R1` upward by decades |
| Setup string, table 3-8 | `Z0B0G0M0K2S3T5` |
| Conversion, table 3-16 | 106 ms at `S3`, 6.5 digits |
| Reading tags, figure 3-6 | `DCV` `ACV` `OHM` `OCO` **`DCI`** `ACI` `dBV` `dBI` |

Inference had two of those wrong before the manual was read, and both are worth
remembering: it put the lowest amps range at 3 mA, and the conversion at 350 ms.

`S3` rather than `S2` because the readings are overlapped and the 34401A beside
it takes 393 ms, so the 196 finishes inside that window either way. The extra
digit is free.

The setup letters in order: relative off, so a REL left on the front panel
cannot offset every reading; readings from the A/D rather than the buffer; send
the prefix that flags an overflow; SRQ mask cleared; EOI on and bus hold-off
off, which is what lets the second meter be triggered while this one is
converting; 6.5 digit resolution; convert once per `X`.

### The status words

`U0` returns the machine status word: `196` and then one digit per programmed
setting. The digit positions, counted after the prefix, were mapped on this
bench by toggling one setting at a time and diffing the reply. They live in the
profile as `StatusMap`:

| setting | digit |
|---|---|
| `F` function | 3 |
| `K` EOI and hold-off | 6 |
| `R` range | 18 |
| `S` resolution | 19 |
| `T` trigger | 20 |
| `Z` relative | 27 |

`U1` returns the error condition word, and reading it is what clears the bits.
Bit 1 is TRIG ERROR and bit 11 is IDDC, measured with `F9X` and `Q9X`.

**Setup is verified against the machine word, not the error word.** A phantom
error bit can surface an exchange or two after whatever caused it, so
`ddcVerifySetup` reads `U0` back and compares digits against what was sent. The
error word says what the meter has been through; the machine word says what it
is in.

## Agilent 34401A

SCPI rather than the Keithley letter dialect, so the profile carries
`Dialect = "scpi"`. Read off manual 34401-90004. Ranges are 100 mV to 1000 V,
10 mA to 3 A, 100 Ω to 100 MΩ. Front panel address default is 22.

- `openMeter` uses an LF read terminator, not CR LF, and sends `SYST:REM` on an
  `ASRL` resource only.
- `identifyMeter` uses `*IDN?`, whose reply carries the model in the middle
  rather than at the front.
- `assertMeterHappy` drains `SYST:ERR?` until it reads `+0`, rather than popping
  one entry, so a setup with several rejected commands reports all of them in
  one run.
- `meterTrigger` and `meterFetch` are `INIT` then `FETC?`, which is what makes
  the two conversions overlap.
- `scpiDecode` takes a bare number; overflow is 9.9e37 and must not reach the
  CSV.

**`CONF` resets integration time, autozero and input impedance to that
function's defaults**, which the manual is explicit about. Everything in
`scpiConfigure` is therefore sent after the `CONF`, never concatenated before
it, and a mid-sweep range change uses `RANGe` alone so the setup survives.

`DMM_NPLC` and `DMM_LINE_HZ` are 34401A only. 10 NPLC at 60 Hz is 167 ms, and
`DMM_ZERO_CORRECT` maps to `ZERO:AUTO`, which costs a second conversion, so a
reading is about 393 ms against the 196's 106 ms.

`TRIG:DEL AUTO` is not a command. `TRIGger:DELay` takes seconds, `MINimum` or
`MAXimum`; the automatic delay is the separate node `TRIGger:DELay:AUTO
{OFF|ON}`. The short form is `-224, Illegal parameter value`, manual page 80.

## Ranges

Ranges are measured rather than assumed. `probeRanges` reads the `OPEN` and
`SHORT` states on autorange before the run: those two states bound the whole
sweep, since every other state is one of them with resistance added. `ISC_FULL`
and `VOC_FULL` default to zero, meaning measure it, and a number pins the range
instead.

During the sweep both meters follow the reading, `followRange`. It widens at
90% of range or on an overflow and narrows under 8%, jumping straight to the
range that fits; the gap between those thresholds is the hysteresis that stops a
reading parked on a boundary from re-ranging at every state. An overflow is
recovered by widening and reading again rather than logged as a fault.

The voltmeter follows for resolution: a 34401A carries 0.0035% of reading plus
0.0005% of range, so at 10 mV on the 10 V range the floor term is 50 µV against
0.35 µV of gain error. The ammeter follows for survival: a pinned range cannot
track illumination that drifts, and five overflows in a row abort the run.

`assertConfig` warns when `ISC_FULL` sits far below the ammeter's lowest range
and refuses when it sits above the highest.

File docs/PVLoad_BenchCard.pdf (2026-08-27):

## PVLoad-R1 Bench Card

WIRING THE ARDUINO
Connect ten wires from the Arduino to the 10-pin header on the board. Pin 1 is the square pad.
1 | 5V | 5 V
2 | GND | GND
3 | D6 | K1 drive
4 | D7 | K2 drive
5 | D8 | K3 drive
6 | D9 | CS U2
7 | D10 | CS U1
8 | D11 | SDI
9 | D12 | SDO
10 D13 | SCK
On the Uno, 5V and GND are on the power side. D8 to D13 are the six pins nearest the USB socket.
THE THREE BANANA JACKS
J1, red. PV+, the cell's positive.
J2, red. +24 V from the bench supply.
J3, black. Ground. Connect both the supply negative and the cell negative here. Use a stacking plug. Do not force two plugs into one jack.

POWER UP
1. 24 V on
2. 5 V on (plug in the Arduino)
3. PV− → J3
4. PV+ → J1
5. illuminate the cell
POWER DOWN
1. darken the cell
2. PV+ out of J1
3. PV− out of J3
4. Arduino out (5 V off)
5. 24 V off

WHAT ON AND OFF MEAN
Do not unplug anything from the board to turn a supply on or off. The supply leads stay in J2 and J3. The ten header wires stay on the Arduino.
For 24 V, press the output button on the bench supply. If the supply has no output button, put the black lead in J3 first, then push the red lead into J2.
For 5 V, plug or unplug the USB cable at the laptop end. Stop the script first.

THE LIGHT IS YOURS TO SET
The script does not control the illumination and does not know what it is. Set the lamp, run the sweep, change the lamp, run it again. Each run writes its own timestamped CSV. Put the lamp setting in RUN_TAG first: nothing else records it, and two runs at different light are otherwise indistinguishable.

USING THE HANDHELD METER
Put the black lead in the socket marked COM. Put the red lead in the socket marked VΩ. Never use the 10A socket. That socket makes the meter a piece of wire and shorts J1 to J3.
Turn the dial to ohms (Ω) to read the board's resistance across J1 and J3. Turn it to DC volts (V with a straight line over dashes) to probe pins against ground.

CABLES TO THE LAPTOP
Arduino. A standard USB printer cable, A to B.
Bench supply. Two banana leads to J2 and J3. Set 24.0 V and a current limit near 100 mA.
The two bench meters. A Keithley 196 and an Agilent 34401A. Neither has USB. Each has one GPIB socket, the wide connector with two screws. Use a single USB to GPIB adapter, Keysight 82357B. Plug the adapter into the laptop. Run a GPIB cable from the adapter to the first meter. GPIB connectors stack, so run a second GPIB cable from the first meter to the second. Both meters share the one adapter.
Give each meter its own address before you connect them. Two meters cannot share one. Whatever you choose, it has to match DMM_V_ADDRESS and DMM_I_ADDRESS in the script.

WHICH METER GOES WHERE
Put the 34401A on volts and the 196 on amps. Both are ordinary DMMs on current, so that side is a wash. On volts they are not: at the open-circuit point the board presents 470 kΩ, and a 10 MΩ meter across it reads Voc about 4.5% low.
The 34401A can be told to raise its input above 10 GΩ, and the script sends that command to whichever meter is the voltmeter. The 196 has no such command, and the 30 V range a 9 V cell lands on is 10 MΩ.
Tell the script which is which with DMM_V_MODEL and DMM_I_MODEL. It asks each meter its model at startup and stops if they disagree.

CONNECTING THE METERS TO THE CELL
The amps meter goes inside the wire. Current must flow through the meter. Cut the wire from the cell's + terminal to J1 and put the meter in the break. Current does not go into the volts terminal on either meter. On the 196 use AMPS and LO; on the 34401A use the current terminal, the one with the fuse symbol, and LO.
cell + | → AMPS or I
LO | → J1
The volts meter goes across the cell. Cut nothing. Two leads touch the cell's terminals. On the 196 use VOLTS OHMS HI and LO; on the 34401A use HI and LO.
HI | → cell +
LO | → cell −
Clip these to the cell's own leads, not to J1 and J3. On the jacks the reading passes through the amps meter and comes out low by its burden drop, which is tens of millivolts on either of these meters. Both read current across a shunt.

METER FRONT PANELS
Both meters duplicate their terminals on the back. The 196 chooses between the two sets with a rear switch marked INPUT; the 34401A with a lit button on the front. If readings do not move, check that first.
GPIB address on the 196: press PRGM, 3, 1, set the number with the data entry keys, press ENTER. Factory 7, range 0 to 30.
GPIB address on the 34401A: press blue Shift, then I/O. Step to HP-IB ADDR with the arrow keys, set the number, press Enter. Factory 22, range 0 to 31.
REMOTE lights while the laptop drives a meter. LOCAL takes it back. The 34401A's current input has its own fuse, reachable from outside; a blown one reads zero current with nothing else wrong.

DO NOT. Never leave the cell connected and lit while 24 V is off. If 5 V is on and 24 V is off, the cell's current flows into the chip and destroys it. Connect the cell last and disconnect it first.

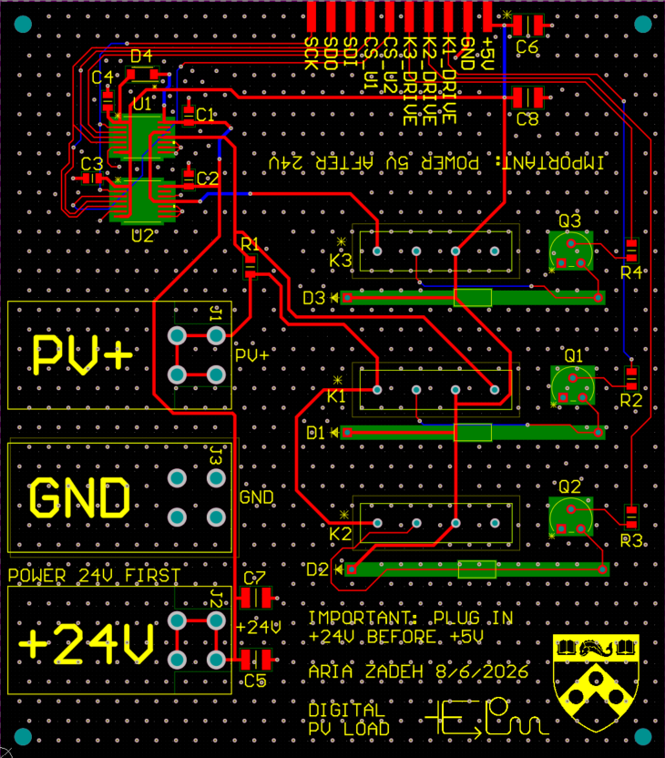
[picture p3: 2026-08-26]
docs/img/pcb-top-no-pour.png

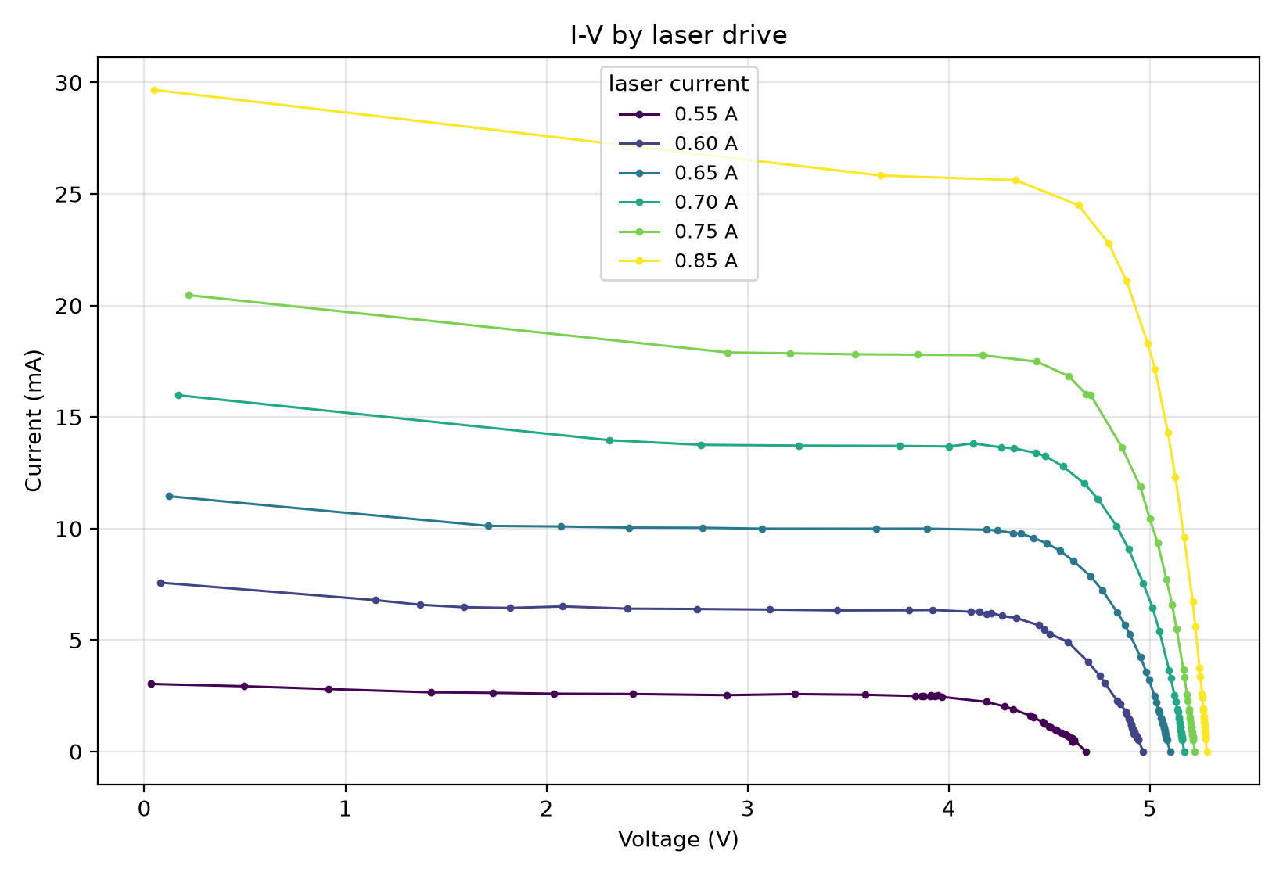
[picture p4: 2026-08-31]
figures/family_iv.png

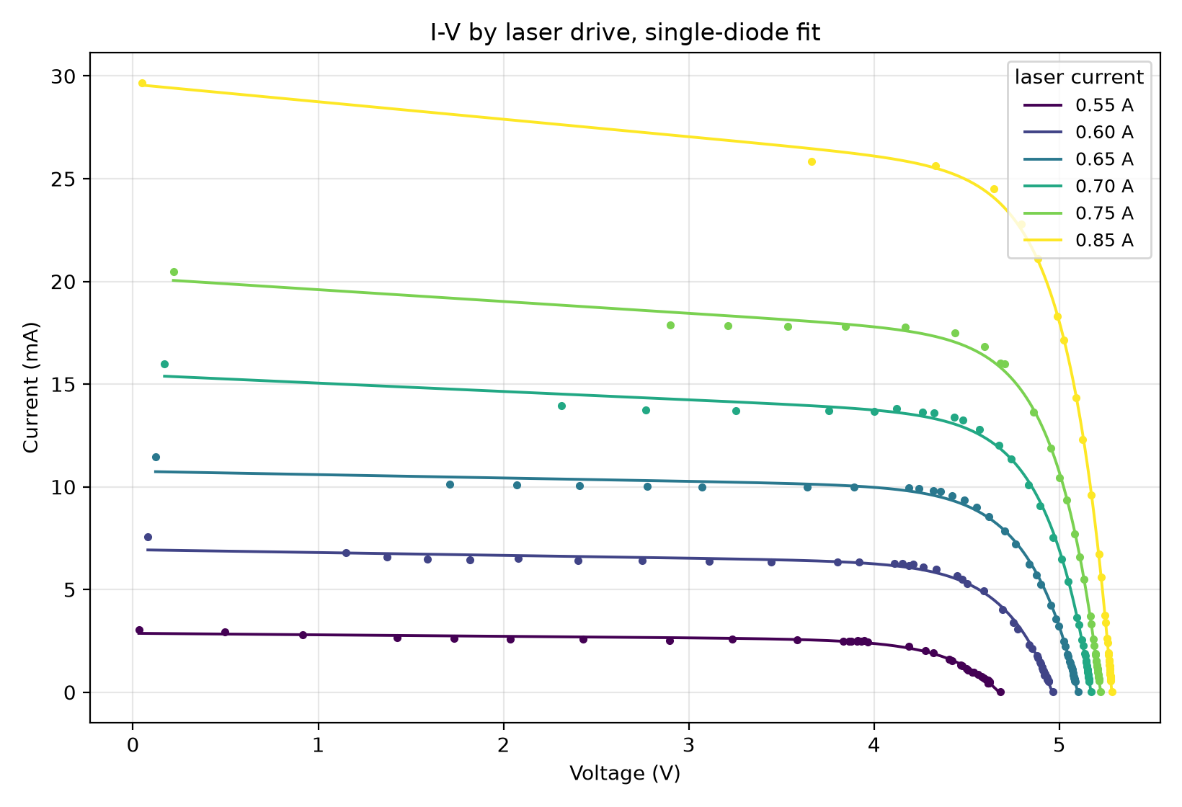
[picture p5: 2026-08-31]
figures/family_iv_fit.png

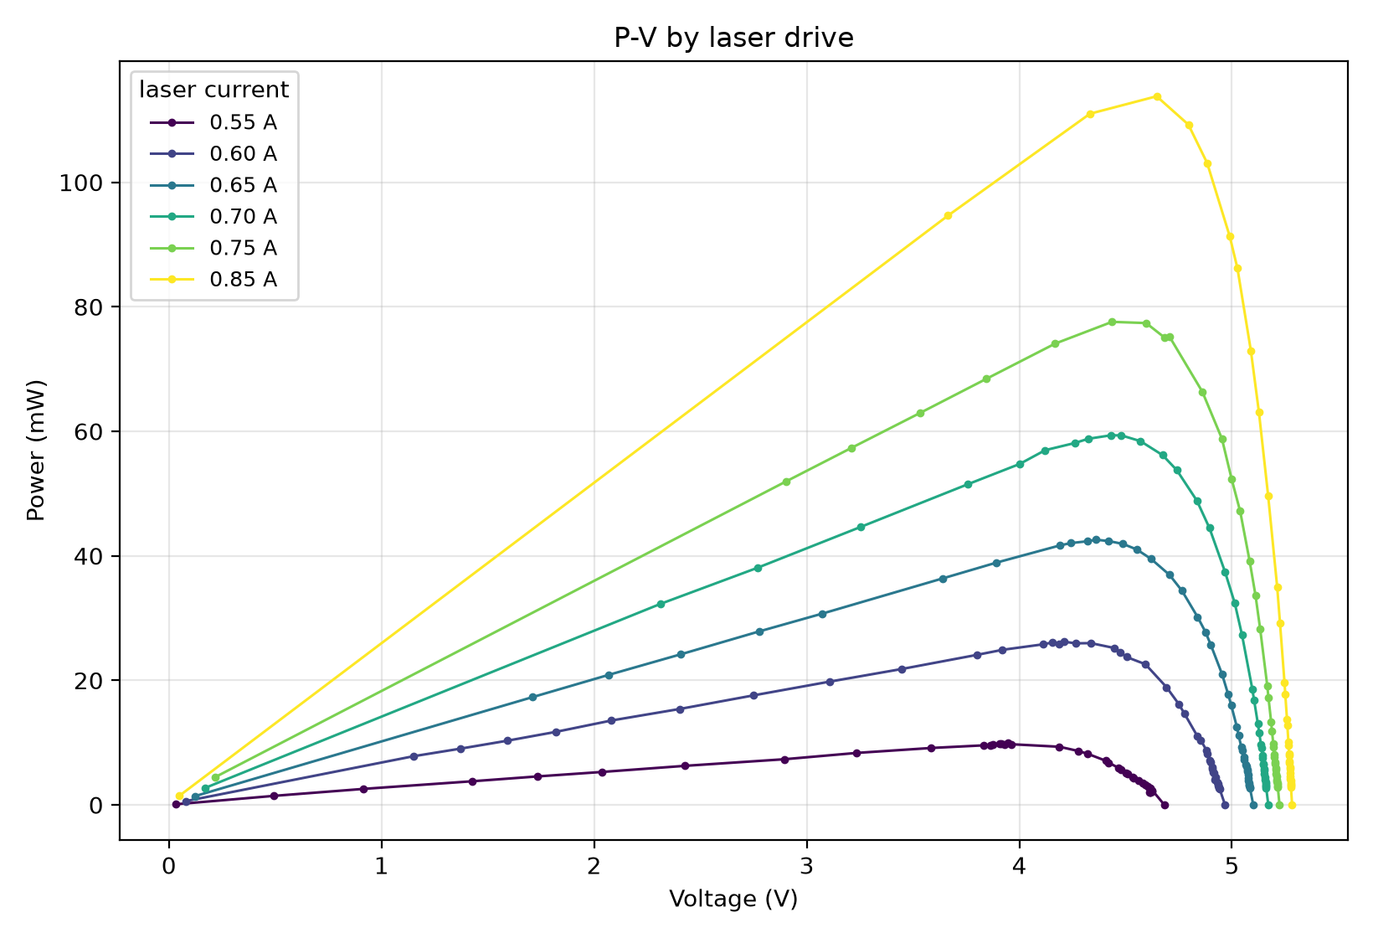
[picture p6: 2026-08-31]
figures/family_pv.png

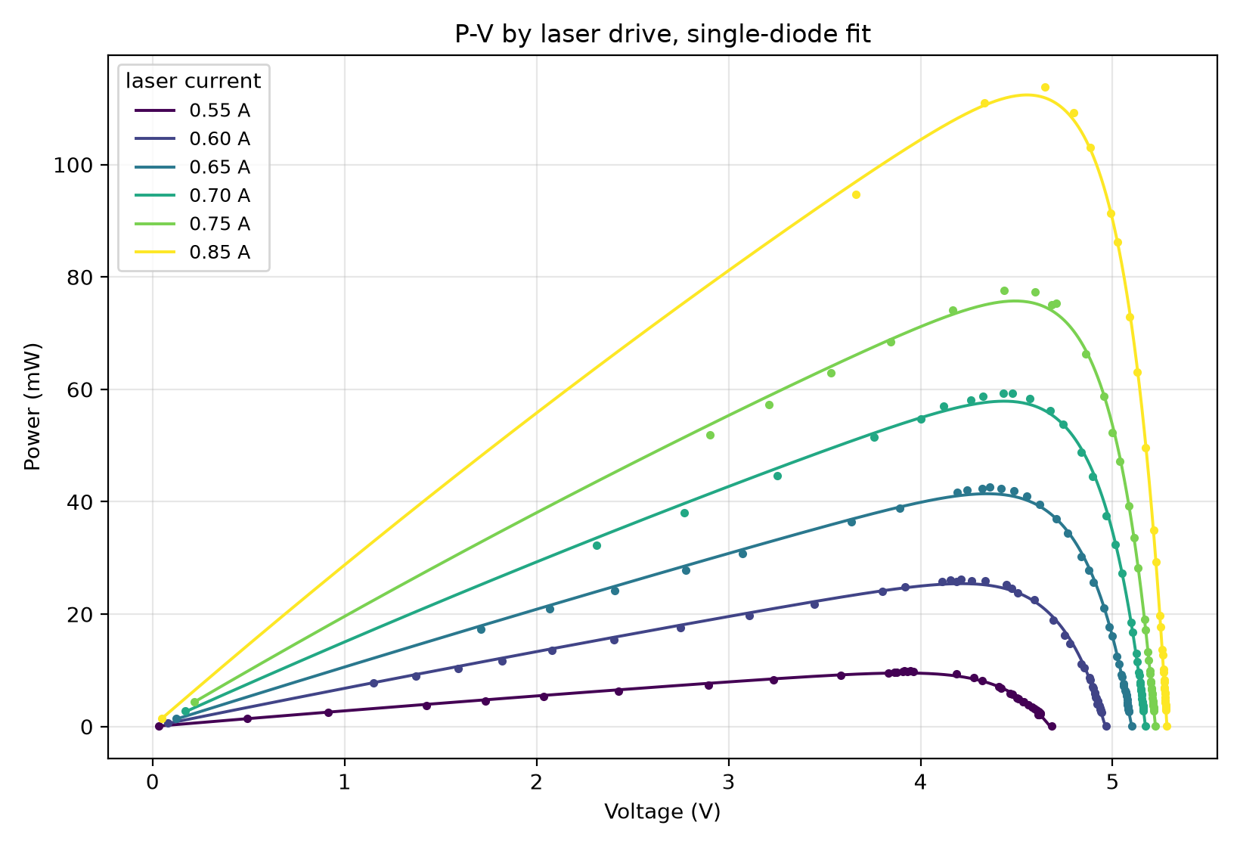
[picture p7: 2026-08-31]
figures/family_pv_fit.png

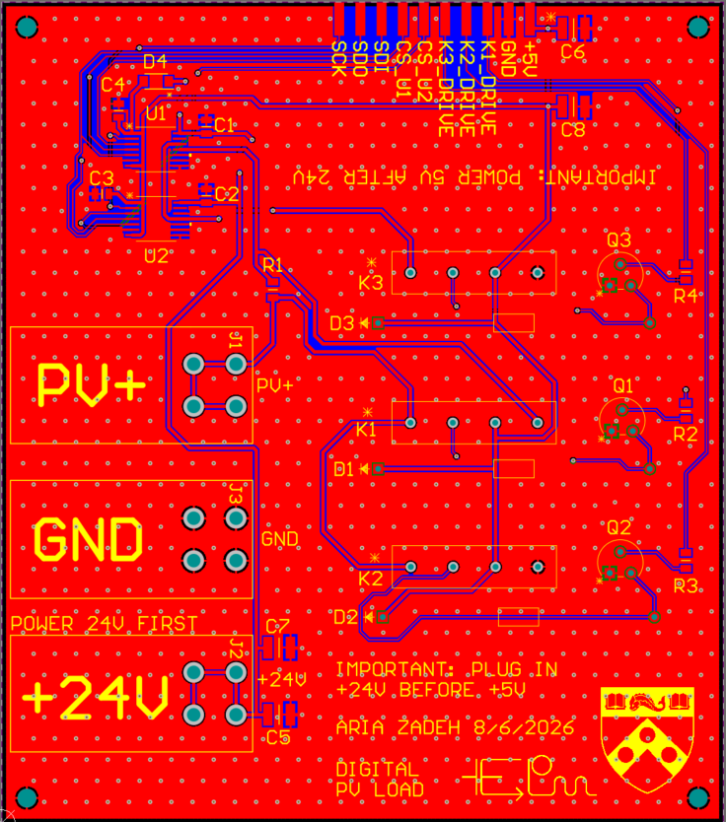
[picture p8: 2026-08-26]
docs/img/pcb-top.png

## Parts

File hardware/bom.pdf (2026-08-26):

# Digital PV Load BOM

Need is the quantity fitted on one board. Buy is the quantity to order, including spares.

Ref | Manufacturer part | Need | Buy | DigiKey product page
U1, U2 (Digipot) | MCP41HV51-502E/ST | 2 | 3 | MCP41HV51-502E/ST Microchip Technology | Digital Potentiometers | DigiKey (https://www.digikey.com/en/products/detail/microchip-technology/MCP41HV51-502E-ST/3872225)
K1 to K3 (Relay) | HE3621A0540 | 3 | 4 | HE3621A0540 Littelfuse Inc. | Reed Relays | DigiKey (https://www.digikey.com/en/products/detail/littelfuse-inc/HE3621A0540/3525328)
Q1 to Q3 (Transistor) | 2N3904BU | 3 | 5 | 2N3904BU onsemi | Single Bipolar Transistors | DigiKey (https://www.digikey.com/en/products/detail/onsemi/2N3904BU/1413)
D1 to D3 (Diode) | 1N4148 | 3 | 5 | 1N4148 onsemi | Single Diodes | DigiKey (https://www.digikey.com/en/products/detail/onsemi/1N4148/458603)
R1 (470K Resistor) | RC0805FR-07470KL | 1 | 10 | RC0805FR-07470KL YAGEO | Chip Resistor - Surface Mount | DigiKey (https://www.digikey.com/en/products/detail/yageo/RC0805FR-07470KL/727977)
R2 to R4 (1K Resistor) | RC0805FR-071KL | 3 | 10 | RC0805FR-071KL YAGEO | Chip Resistor - Surface Mount | DigiKey (https://www.digikey.com/en/products/detail/yageo/RC0805FR-071KL/727444)
C1 to C4 (0.1uf Capacitor) | CL21B104KBCNNNC | 4 | 10 | CL21B104KBCNNNC Samsung Electro-Mechanics | Ceramic Capacitors | DigiKey (https://www.digikey.com/en/products/detail/samsung-electro-mechanics/CL21B104KBCNNNC/3886661)
C5 to C8 (10uF Capacitor) | CL32B106KBJNNNE | 2 | 10 | CL32B106KBJNNNE Samsung Electro-Mechanics | Ceramic Capacitors | DigiKey (https://www.digikey.com/en/products/detail/samsung-electro-mechanics/CL32B106KBJNNNE/3889045)
J1, J2 (Red Banana Jack) | CT3151-2 | 2 | 3 | CT3151-2 Cal Test Electronics | Jacks, Plugs | DigiKey (https://www.digikey.com/en/products/detail/cal-test-electronics/CT3151-2/6005442)
J3 (Black Banana Jack) | CT3151-0 | 1 | 2 | CT3151-0 Cal Test Electronics | Jacks, Plugs | DigiKey (https://www.digikey.com/en/products/detail/cal-test-electronics/CT3151-0/6005441)
MCU1 (Header) | PRPC010SAAN-RC | 1 | 2 | PRPC010SAAN-RC Sullins Connector Solutions | Headers, Male Pins | DigiKey (https://www.digikey.com/en/products/detail/sullins-connector-solutions/PRPC010SAAN-RC/2775244)
D4 (SCHOTTKY Diode for protection) | 1N5819HW-7-F | 1 | 4 | https://www.digikey.com/en/products/detail/diodes-incorporated/1N5819HW-7-F/815283 (https://www.digikey.com/en/products/detail/diodes-incorporated/1N5819HW-7-F/815283)

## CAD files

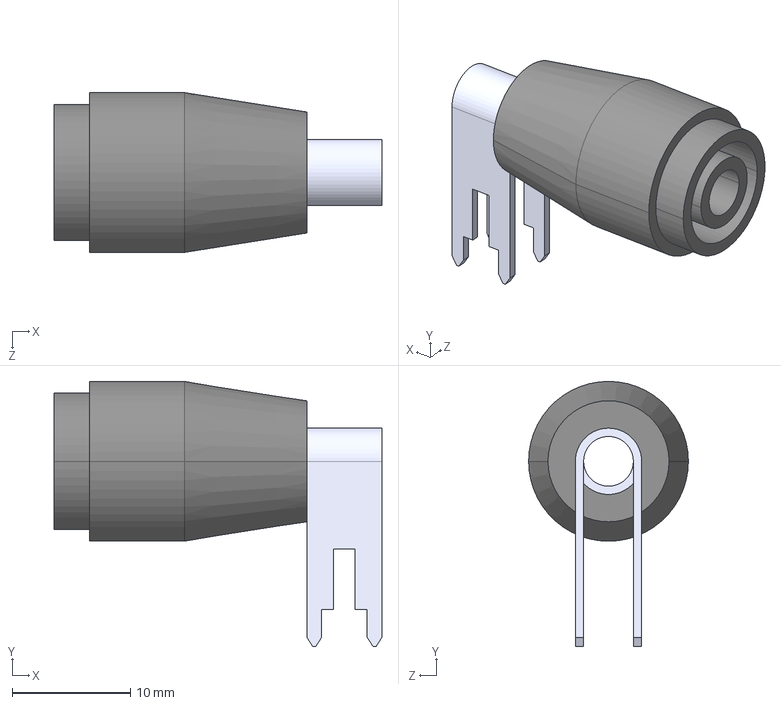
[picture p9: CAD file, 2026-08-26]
hardware/altium/3D Models/CT3151-0.stp
27.7 x 22.4 x 13.5 mm

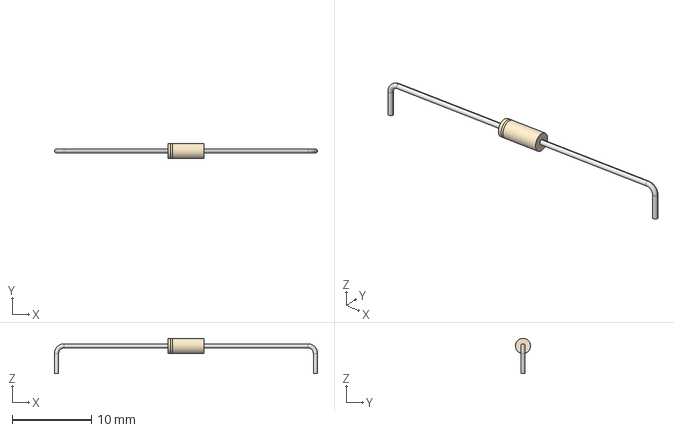
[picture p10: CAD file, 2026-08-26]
hardware/altium/External Libraries/1N4148 (Diode)/AXIAL_017AG_T26_ONS.step
33.1 x 1.91 x 4.45 mm

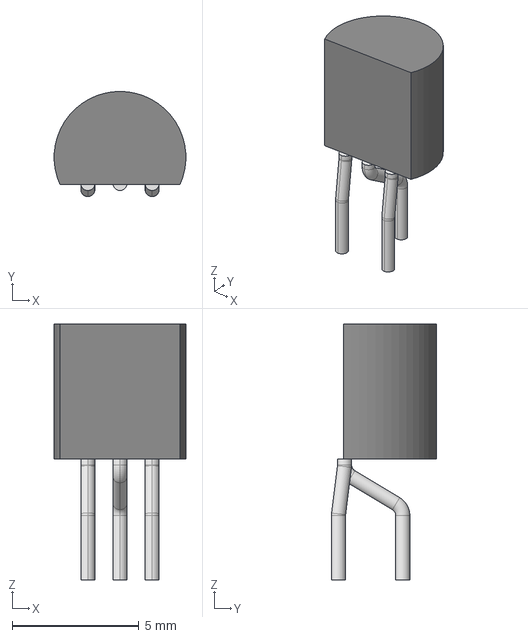
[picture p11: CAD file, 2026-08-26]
hardware/altium/External Libraries/2N3904BU (Transistor)/AltiumDesigner/TO-92_FAS.step
5.20 x 4.15 x 10.1 mm

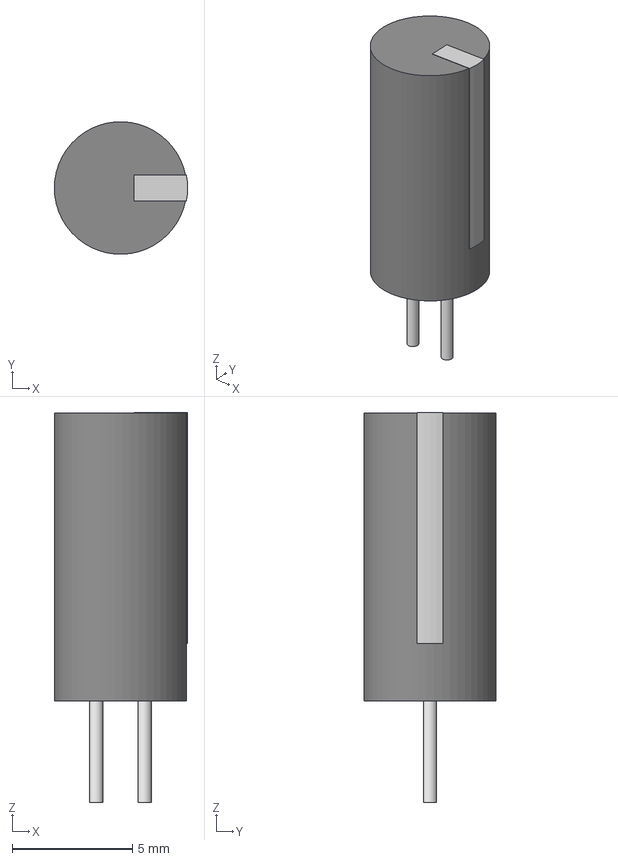
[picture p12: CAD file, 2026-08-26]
hardware/altium/External Libraries/CAP_PAN_5X11_PAN (10uF Capacitor)/CAP_PAN_5X11_PAN.step
5.55 x 5.51 x 16.2 mm

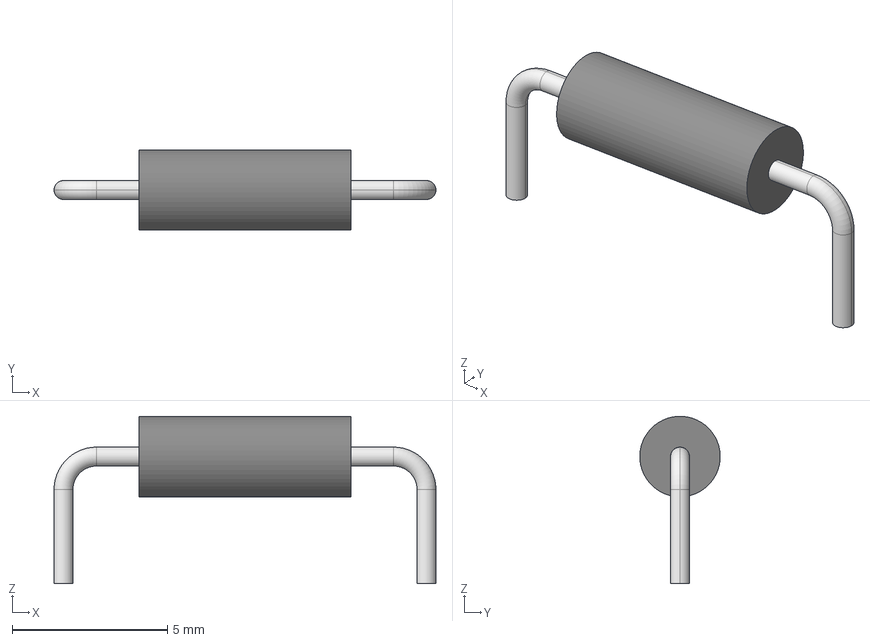
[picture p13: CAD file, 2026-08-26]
hardware/altium/External Libraries/CFR-25JB-52-1K (1K Resistor)/YAG_CFR25_YAG.step
12.3 x 2.59 x 5.38 mm

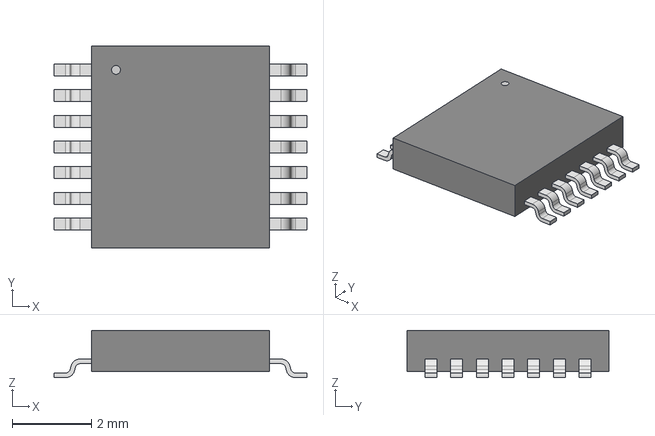
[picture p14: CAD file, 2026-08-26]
hardware/altium/External Libraries/MCP41HV51_502E_ST (Digipot)/AltiumDesigner file/TSSOP14_MC_MCH.step
6.40 x 5.11 x 1.20 mm

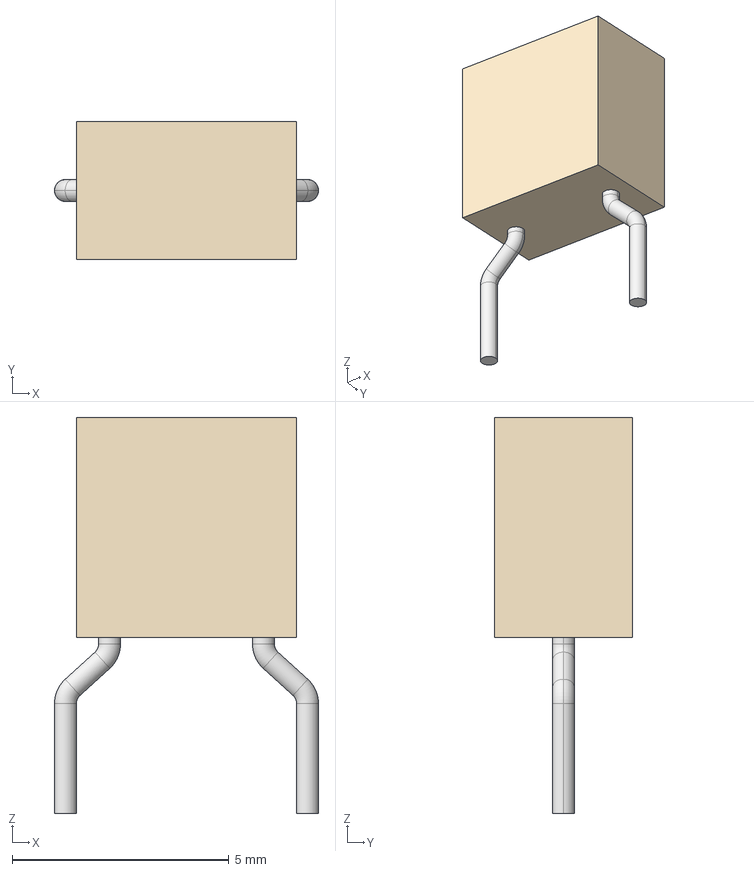
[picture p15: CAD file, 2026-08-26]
hardware/altium/External Libraries/SR215C104KAR (0.1uF Capacitor)/CAP_SR21_AVX.step
6.10 x 3.18 x 9.14 mm

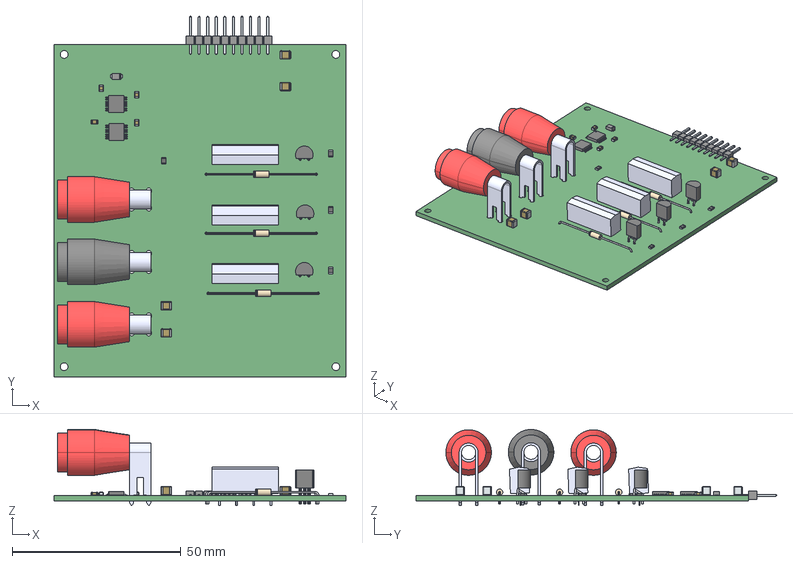
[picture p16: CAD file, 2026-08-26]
hardware/altium/PVLoad.step
86.5 x 106.8 x 22.5 mm
PinKIdent
PinK
PinA
term1 x 4
term2 x 4
LeadsArray
HE3621A0540 x 3
CT3151-0

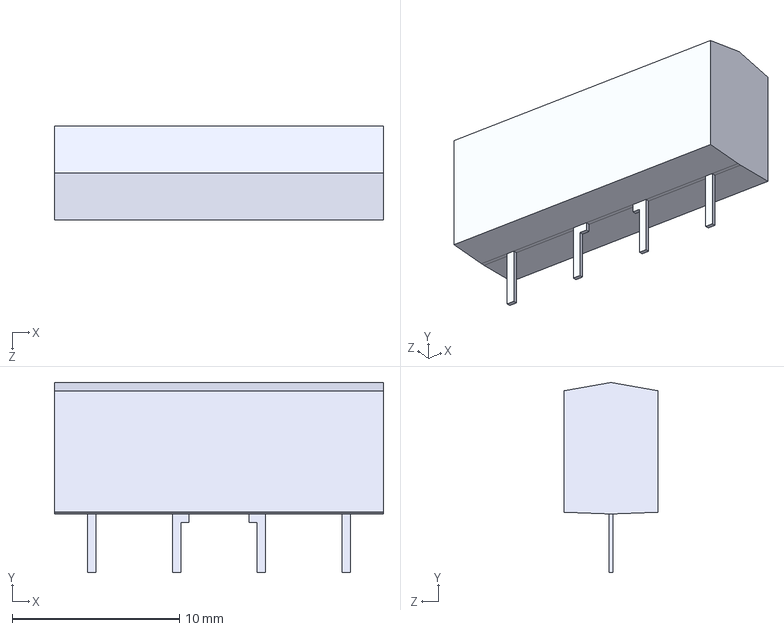
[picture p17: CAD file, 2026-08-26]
hardware/altium/3D Models/HE3621A0540.stp
19.7 x 11.4 x 5.65 mm

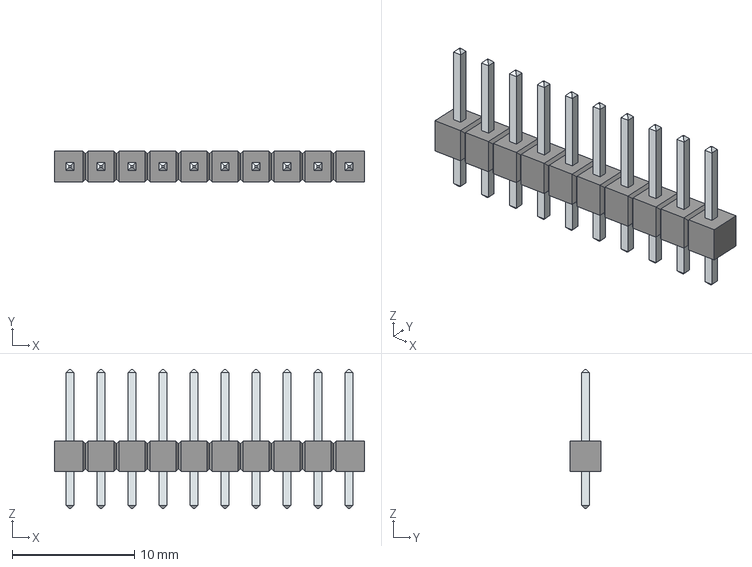
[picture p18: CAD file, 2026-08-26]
hardware/altium/3D Models/PREC010SAAN-RC.stp
25.4 x 2.54 x 11.4 mm
LeadsArray

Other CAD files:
hardware/altium/External Libraries/CFR-25JB-52-470K (470K Resistor)/YAG_CFR25_YAG.step
hardware/altium/External Libraries/MCP41HV51_502E_ST (Digipot)/TSSOP14_MC_MCH.stl
hardware/altium/3D Models/CAP_SR21_AVX.step
hardware/altium/3D Models/AXIAL_017AG_T26_ONS.step
hardware/altium/3D Models/YAG_CFR25_YAG 470K.step
hardware/altium/3D Models/CAP_PAN_5X11_PAN.step
hardware/altium/3D Models/CT3151-2.STEP
hardware/altium/3D Models/YAG_CFR25_YAG 1K.step

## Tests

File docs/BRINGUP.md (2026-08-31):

# Bring-up log, PVLoad-R1

What has actually been measured on the assembled boards. Design rationale is in
[DECISIONS.md](DECISIONS.md) and the hardware reference is
[HARDWARE.md](HARDWARE.md); neither is repeated here.

Two boards were built to the same design. **Board 2 is sound and is the one to
use.** Board 1 has two faults, recorded at the end.

---

## Bench

No cell attached. A handheld meter in ohms across J1 and J3 stands in for the
cell, so every reading is the load a cell would see. 24 V bench supply on J2 and
J3. Arduino Uno on COM4 through the 1x10 header. MATLAB drives it and `RUN`
selects the mode.

`RUN = "verify"` is the seven-hold check for a freshly assembled board, and its
last two holds are the K3 test. `"ramp"` walks the whole sweep slowly enough to
follow on a handheld. `"wiper"` isolates the wiper resistance. All three touch
the board only, with no cell and no bench meters involved.

## Power order

Up: 24 V, then the Arduino. The Arduino's 5 V pin is the board's logic and coil
supply, so plugging it in is what raises the 5 V rail.

Down: Arduino, then 24 V.

The first session ran with the 24 V output switched off. The ladders still
measured correctly, because the resistor string is passive and needs no rail,
but the wiper switches had no analog supply and read several hundred ohms to a
kilohm. Every wiper figure from that session was discarded. A reading that looks
like a large unexplained series resistance is worth checking against the supply
before it is chased into the board.

---

## Host and meter link

MATLAB reaches the meter. The adapter is a Keysight 82357B and the bus runs on
Keysight IO Libraries, so `instrhwinfo('visa')` lists `agilent`, `keysight` and
`ni`, and `visadevlist` returns one instrument at `GPIB0::1::INSTR`. Getting
there needed the C++ runtime fix in [TROUBLESHOOTING.md](TROUBLESHOOTING.md);
none of it was a VISA setting.

The instrument answers, and it is the 196:

| Query | Reply |
|---|---|
| `U0X` | `1961000000010000000043600000000` |
| `U1X` | `196000000000000000000000000` |
| bare read | `NDCV-000.0001E+0` |

`U0` opens with the model number, which agrees with `DMM_R_MODEL = "196"` and with
`DMM_R_ADDRESS`. `U1` is all zeros after the prefix, so nothing is latched. The
reading is DC volts at −0.1 mV, which is the meter sitting on its own leads.

What that does not prove: only `U0` and `U1` have been sent. The rest of the 196
profile, `F2` for ohms and the setup string `Z0B0G0M0K2S2T5`, has never reached
the instrument. The first `RUN = "ohms"` is what tests it, and the `U1` query
that follows the setup string is what catches a letter the 196 does not take.

A fresh session has to be flushed before the first read or that read times out.
Reproduced on every run, both write terminators. `openMeter` flushes.

---

## Board 2, `RUN = "verify"`

| Hold | State | Measured | Proves |
|---|---|---|---|
| 1 | `OPEN` | 470 kΩ | R1, K1 releasing |
| 2 | `SHORT` | 0.004 Ω | K2 closing |
| 3 | `FULL` 0, 0 | 310 Ω | K1 closing, both wipers |
| 4 | `FULL` 255, 0 | 5.27 kΩ | U1 ladder |
| 5 | `FULL` 255, 255 | 10.22 kΩ | U2 ladder |
| 6 | `LOW` 0, 0 | 155.8 Ω | K3 closing |
| 7 | `LOW` 0, 255 | 155.8 Ω | K3 closing, proved |

The SPI self-test passes on both chips, reading wiper registers back at codes 0,
85, 170 and 255.

Everything derived from those seven numbers:

| Quantity | Value | Note |
|---|---|---|
| U1 ladder | 4960 Ω | hold 4 − hold 3 |
| U2 ladder | 4950 Ω | hold 5 − hold 4 |
| U1 wiper | 155.8 Ω | hold 6 − hold 2 |
| U2 wiper | 154.2 Ω | hold 3 − hold 6 |
| Probe and jack offset | 0.004 Ω | hold 2 |

Both ladders land within 1% of each other and about 1% under the 5 kΩ nominal,
comfortably inside the ±20% tolerance, so `R_AB_NOMINAL` stays at 5000. Both
wipers agree to 1% and sit between the datasheet's 75 Ω typical and 200 Ω
maximum. `R_WIPER` is now 155, measured rather than assumed.

Hold 7 is the one that matters for K3. `LOW` shorts U2 out, so U2's code cannot
reach the terminals and hold 7 has to equal hold 6. It does.

## Measuring with a handheld

A handheld carries its probes, its clips and both banana jacks in every reading.
On board 2 with a stacking plug at J3 that came to 0.004 Ω, which is negligible.
On board 1 it was 30–80 Ω and drifted between runs.

Prefer differences anyway. Every derived figure above is one, so none of them
depend on the probe path being good.

---

## Board 1 faults

**K3 does not close.** Confirmed by holding `LOW` and writing U2 to 0 and 255
alternately, which is what the last two holds of `RUN = "verify"` do. With K3
closed U2 is shorted out and all four holds must read alike. They did not:

| Hold | U2 code | Measured |
|---|---|---|
| A | 0 | 308 Ω |
| B | 255 | 5.27 kΩ |
| C | 0 | 308 Ω |
| D | 255 | 5.27 kΩ |

U2's whole ladder appears and disappears with its code, so U2 is in the path in
`LOW` as well as in `FULL` and K3 never operates.

The drive is not at fault. `setMode` raises D8 for `LOW`, matching section 4 of
HARDWARE.md, and Q3's collector swings 5 V to 0.04 V with the pin. A collector
that reaches 0.04 V rules out a reversed flyback diode, which would clamp it near
4.3 V, and a clean 5 V when off means the coil is continuous. So the coil is
driven at about 4.96 V and the contact still does not close: either the relay
itself, or its COM and NO pins not reaching the board.

This failure is invisible to every other test. It only makes `LOW` and `FULL`
read alike, which looks like a component with no resistance rather than a relay
that never moved.

**About 60 Ω in the `SHORT` path.** Board 1 reads 30–80 Ω at `SHORT` and drifts
between runs; board 2 reads 0.004 Ω through the same leads and the same meter.
The leads are therefore not the cause and it is on the board — K2, its joints, or
the jacks.

---

## Both meters, `RUN = "meters"`

The bench runs an Agilent 34401A on volts at `GPIB0::22::INSTR` and a Keithley
196 on amps at `GPIB0::1::INSTR`, through one Keysight 82357B. `visadevlist`
names the 34401A and leaves the 196's columns empty, which is what a meter with
no `*IDN?` looks like.

Both identify:

| Query | Reply |
|---|---|
| `*IDN?` | `HEWLETT-PACKARD,34401A,0,11-5-2` |
| `U0X` | `1961000000010000000043600000000` |

Three faults came out of getting from there to ten readings. All three were in
the script rather than on the bench, and the order they surfaced in matters,
because two of them cancelled.

**`TRIG:DEL AUTO` is not a 34401A command.** `SYST:ERR?` answered
`-224,"Illegal parameter value"`. Manual page 80 gives `TRIGger:DELay
{<seconds>|MINimum|MAXimum}` and `TRIGger:DELay:AUTO {OFF|ON}` as separate
commands, so `AUTO` is a node and not a parameter. Corrected to
`TRIG:DEL:AUTO ON`.

**Under `T5` every command string leaves a reading behind.** The trailing `X`
that executes a setup string is also the trigger, so the conversion it starts is
never collected and the next query reads it instead of its own answer. This
showed up as `U1` answering `NDCI-00.00009E-3`, a current reading where the
error word should have been. Queries now flush the input first, and
`configureMeter` flushes again when it is done, so the sweep starts on an empty
buffer. The duplicate call that configured the ammeter twice is gone as well.

**The 196 tags DC amps `DCI`.** Figure 3-6: `DCV`, `ACV`, `OHM`, `OCO`, `DCI`,
`ACI`, `dBV`, `dBI`. The decoder had been matching `DCA`, which this meter never
sends, so a current reading would have decoded to NaN. The tag list now lives in
the profile.

The run that produced ten clean readings did so with two of these still
outstanding, which is worth remembering. A `flush` that cleared the output buffer
as well as the input had discarded the `F3R3...` setup string, so the 196 was
still in its power-on DC volts; `U1` then came back clean because no bad command
had reached it, and the volts reading decoded because `DCV` was in the old tag
list. The console read `I = -0.000400 A` and the number was a few hundred
microvolts of float on an open input. **It was caught by looking at the front
panel, which said volts on both meters.** Nothing in the software noticed.

---

## Open

**The 196 command profile is now read off manual 196-901-01 Rev D**, not
inferred: functions from section 3.9.2, ranges from table 3-9, the setup string
from table 3-8, the 24 ms conversion from table 3-16, the reading tags from
figure 3-6. Inference had the lowest amps range at 3 mA where it is 300 uA, and
the conversion at 350 ms where it is 24 ms.

**The second sweep aborted on drifting illumination, and two of the three
causes were in the software.** Run `20260828_163338`, tagged `ILASER0p45`, at
0.45 A of laser drive. The probe measured Isc 123.8 µA and an `OPEN` state of
3.5945 V, so the extra 0.03 A of drive had nearly doubled the photocurrent and
brought the knee from 4.5× out of reach to 2.5×. 512 states reached disk before
the abort at state 541.

What the saved rows show, against the clock rather than against the load:

| time | state | current |
|---|---|---|
| 16:33:40 | 1 | 125.2 µA |
| 16:38:41 | 257 | 158.1 µA |
| 16:47:35 | 512 | 183.6 µA |

The current rose 1.66× over fourteen minutes while the load resistance was
*increasing*, which is the opposite of a cell moving along its own curve. The
illumination was still coming up the whole run. It eventually passed the 300 µA
range the probe had pinned, six overflows in a row met `DMM_MAX_FAULTS`, and
the sweep stopped by design with everything up to the last block boundary
saved.

Two of mine made it worse than it needed to be. The ammeter was pinned on the
argument that a cell's current is flat across a sweep, which is true of the
cell and not of the bench; it follows its range now, the way the voltmeter
already did. Worse, `measureSettle` read the drift as settling and turned 2.5 s
at 10.3 kΩ into 35 µF of cell capacitance. Nothing has 35 µF. That figure then
set the hold for every state, so the run took fourteen minutes instead of six
and gave the drift more than twice as long to work. Drift is told from settling
by where the change sits in the window now, and drift takes no capacitance from
the measurement.

The third cause is not fixable in software: a sweep measures each state at a
different moment, so anything moving on its own tilts the curve. Let the laser
reach equilibrium before starting, judged by the `SHORT` state current on the
196 holding still.

**The first sweep on a cell ran clean and the cell is far dimmer than the board
was sized for.** Run `20260828_145929`, tagged `ILASER0p42`, 0.42 A of laser
drive: 769 of 769 states, no dropped readings, current drift −0.011 %/min over
10.6 minutes. The instrument chain is finished. What it measured:

| | measured | the board wants |
|---|---|---|
| Isc | 64.8 µA | ~1 mA and up |
| V at the top of the ladder | 0.683 V | most of Voc |
| OPEN state current | 7.07 µA, 10.9 % of Isc | under 5 % |

Three consequences, none of them software faults. The ladder stops at 10.3 kΩ
and this cell needs about 36.5 kΩ to reach 70 % of Voc, so the sweep never
leaves the current-source plateau and the knee falls in the gap between the top
of the ladder and R1. The `OPEN` state is not open at this light: 470 kΩ draws
11 % of Isc, so its 3.384 V is a floor under Voc rather than Voc. Fill factor
inherits both errors and means nothing on this run.

More light is the whole fix; the board cannot make a load between 10.3 kΩ and
470 kΩ. Isc of roughly 270 µA puts the knee at the very top of the ladder and
1–2 mA puts it where the sampling is dense, which is 4× to 30× the
illumination of this run.

`ISC_FULL` is now 100 µA, which also moves the 196 off its 30 mA range, where
the cell was living in the bottom 0.2 %, onto 300 µA. `summariseCurve` decides
both of the above from the measurement and says so, and the figure no longer
draws a line from the top of the ladder to the `OPEN` point across the region
nothing was measured in.

**The input-only flush and the `DCI` tag passed on the bench.** Repeated
`RUN = "meters"` with both instruments attached and nothing connected to their
inputs: both identify, both configure, and ten readings sit at noise, volts
around a hundred microvolts and current at one count on the 30 mA range. The
196 read amps on its face and the 34401A volts.

**Every session-open fault traced to one cause: `visadev` sends `*IDN?` on
open.** It cannot be suppressed in R2022a, the 196 cannot execute it without a
trailing `X`, and the stranded fragment eats the next command and latches
IDDCO late. Chased as three separate faults before that: a first command that
vanished, `U0` answered with readings after a power cycle (power-on `T0`,
trigger on talk), and `TRIGGER ERROR` on the display with every command sent
being valid. `primeDdc` absorbs it at open and `ddcVerifySetup` now checks the
`U0` machine word digit against what was sent instead of trusting `U1`; the
word positions were mapped on this bench by toggling one setting at a time
(`F` at 3, `K` at 6, `R` at 18, `S` at 19, `T` at 20, `Z` at 27, counted after
the prefix). Error-word bits measured while at it: `F9X` latches the first
digit, `Q9X` the eleventh. `docs/TROUBLESHOOTING.md` has the full story.

**Overlapped reads are still assumed rather than shown.** Both meters have been
triggered and collected together, but never against a source that would make a
one-state lag visible. Step between two widely separated load states and see
whether the reading follows.

**`CELL_SETTLE` is zero and unmeasured.**

**`ISC_FULL` and `VOC_FULL` are the values the file shipped with.**
The cell is a power-over-fiber receiver for a SiC MOSFET gate driver. Its Voc and
Isc have not been entered.

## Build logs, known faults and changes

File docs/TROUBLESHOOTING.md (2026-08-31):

# Troubleshooting

How to find a fault on an assembled board with a handheld meter and nothing else.
What has actually been found this way is in [BRINGUP.md](BRINGUP.md).

The last two sections cover the host instead of the board: getting MATLAB to see
the meter at all, and getting the first read off it.

---

## Measure differences, not readings

A handheld carries its probes, its clips and both banana jacks in every reading.
On one board that came to 0.004 ohm. On another it was 30 to 80 ohm and moved
between runs. Nothing below a few hundred ohms can be read off the display and
trusted.

Every diagnostic below is a subtraction between two board states. The probe path
is common to both and cancels. Design any new check the same way.

## The diagnostic modes

The first three open the board and nothing else. No cell, no bench meters.

| `RUN` | States | Answers |
|---|---|---|
| `"verify"` | 7 | Is this board sound? |
| `"wiper"` | varies | What is the wiper resistance? |
| `"ramp"` | `RAMP_STEPS` | Does resistance track code across the whole range? |
| `"ohms"` | 769 | The same question, measured rather than eyeballed |

`"ohms"` is `"ramp"` without a person copying numbers off a handheld. It puts one
meter on ohms across J1 and J3, walks every state in the sweep, and writes
the readings to CSV with a plot. Still no cell. It takes one
meter rather than the pair, so it ignores `DMM_ENABLED` and takes its address
from `DMM_R_ADDRESS`. Around twelve minutes at the default `OHMS_SETTLE`.

The meter carries the leads, the jacks and the traces exactly as a handheld does,
so a constant offset of a few ohms across every point is the wiring and not the
board. Read the differences, as everywhere else here.

`"verify"` is the one to run first on anything freshly built. It touches both
chips over SPI, all three relays, both ladders and R1. Its pass conditions are
differences and orders of magnitude, so the probe path does not enter them.

`test_arduino.m` has a fifth, `TEST = "one_pin"`, which drives one pin high and
low on a slow cycle so it can be followed downstream with a voltmeter. Point it
at D6, D7 or D8 in turn. The three relay drives are identical circuits, so a
channel that works is the reference for one that does not.

## What each `"verify"` hold proves

| Hold | State | Pass |
|---|---|---|
| 1 | `OPEN` | about 470 kohm |
| 2 | `SHORT` | lowest of the seven, by far |
| 3 | `FULL` 0, 0 | |
| 4 | `FULL` 255, 0 | hold 4 minus hold 3 is about 5 kohm, the U1 ladder |
| 5 | `FULL` 255, 255 | hold 5 minus hold 4 is about 5 kohm, the U2 ladder |
| 6 | `LOW` 0, 0 | below hold 3 |
| 7 | `LOW` 0, 255 | equal to hold 6, to the ohm |

Hold 7 is the one that catches a dead K3, and no other test on the board can.
`LOW` shorts U2 out, so U2's code must not reach the terminals. A 5 kohm swing
between holds 6 and 7 means the relay never operated.

Wiper resistance falls out of the same seven numbers: hold 6 minus hold 2 is
U1's wiper, hold 3 minus hold 6 is U2's. Both should agree and both should sit
between 75 and 200 ohm.

---

## Traps

**A missing 24 V rail looks like series resistance.** The resistor string is
passive and measures correctly with V+ at zero, but the wiper switches have no
analog supply and read several hundred ohms to a kilohm. The symptom is a large
constant offset with correct ladder slopes. Check the supply's output button
before chasing it into the board.

**A relay that never closes looks like a component with no resistance.** `LOW`
and `FULL` differ only by whether K3 shorts U2 out. If K3 never closes they
contain the same parts and read alike, which presents as a wiper resistance of
zero rather than as a relay fault. Hold 7 of `"verify"` is the only thing that
separates the two.

**`SHDN#` low flattens the sweep silently.** Pulling it low ties the wiper to
P0B. Every software check still passes and every reading is plausible. The tell
is that resistance stops tracking code: check the slope, which should be about
19.6 ohm per step.

**An even `RAMP_STEPS` stride can lock onto one mode.** `LOW` and `FULL` states
alternate through the sorted plan, so a stride that is a whole even number visits
the same mode every time. `RAMP_STEPS = 25` gives a stride of exactly 32 and
shows no `LOW` states at all. Pick a count whose stride is not a whole number.

---

## Localising a relay that will not close

The drive chain for K3, and the same for K1 on D6 and K2 on D7:

```
D8  ->  header pin 5  ->  base resistor  ->  Q3 base
                                            Q3 emitter  ->  GND
                                            Q3 collector -> K3 coil -> +5 V
                              D3 across the coil, band toward +5 V
```

Run `TEST = "one_pin"` with `ONE_PIN = "D8"`, then follow it with a voltmeter
against ground. Probe the same points on a working channel first.

| Point | Pin high | Pin low | If it does not follow |
|---|---|---|---|
| the pin | 5 V | 0 V | Arduino, or the wire to header pin 5 |
| Q base, middle leg | 0.7 V | 0 V | base resistor, or the header connection |
| Q collector, right leg | 0.2 V | 5 V | the transistor |

The collector runs backwards: it goes low when the pin goes high, because the
transistor pulls the coil down to energise it.

Two things are ruled out by those numbers alone. A collector that reaches 0.2 V
means D3 is the right way round, because a reversed flyback conducts as soon as
the transistor turns on and clamps the collector near 4.3 V. A clean 5 V with the
pin low means the coil is continuous, because an open coil leaves the collector
floating and a voltmeter reads near zero.

If the drive follows correctly and the relay still does not close, the coil is
getting its full 4.96 V and the fault is past it. Probe the relay's own legs:
with the board unpowered, one pair reads about 500 ohm and is the coil, the other
pair is COM and NO. Energise the coil and measure COM to NO.

- Under 1 ohm: the relay works and its COM and NO joints are not reaching the
  board. Reflow them.
- About 120 ohm or open: the contact is not closing. The relay is dead. The part
  is obsolete, so a substitute is needed.

## Q pinout

2N3904 in TO-92. Flat face toward you, legs pointing down: left is emitter,
middle is base, right is collector. Confirm without trusting that: the emitter
has continuity to ground, the base is the leg with the 1 kohm resistor, the
collector runs to the relay.

---

## MATLAB cannot see a meter that Connection Expert can

The symptom is a clean split. Keysight Connection Expert lists the instrument
and reads it. MATLAB reports no VISA resources at all:

```
instrhwinfo('visa')            {'ni'}
visadevlist                    Unable to find any VISA resources ...
visadev('GPIB0::1::INSTR')     Resource string is invalid or resource was not found
```

The cause is not VISA configuration. The conflict manager, the preferred
implementation, `ConflictTbl.xml`, the registry and repeated reboots were all
ruled out, and every Keysight DLL loads and is the right architecture.

The cause is the C++ runtime. `MATLAB.exe` lives in `bin\win64`, and Windows
searches a program's own directory first, so the `MSVCP140.dll` that MATLAB
ships there is the one every MATLAB process loads. Keysight IO Libraries is
built against a newer runtime than MATLAB carries. `ktvisa32.dll` then fails its
initialisation with Win32 error 1114, `mwagilentvisa.dll` fails with it, and
MATLAB concludes Keysight VISA is not installed. Connection Expert is a separate
program and loads the system runtime, which is why it works.

Confirm it in three steps.

Compare the two copies. The one under MATLAB will be older:

```
C:\Program Files\MATLAB\R2022a\bin\win64\MSVCP140.dll
C:\Windows\System32\MSVCP140.dll
```

Ask MATLAB to load the adaptor directly. The message names the failure mode,
which the toolbox otherwise hides behind "not installed properly":

```matlab
java.lang.System.load(fullfile(matlabroot, 'toolbox', 'instrument', ...
    'instrumentadaptors', 'win64', 'mwagilentvisa.dll'))
```

A dependency that is merely absent gives "module could not be found". This gives
"A dynamic link library (DLL) initialization routine failed", which means the
library was found, mapped, and refused to start.

Reproduce it outside MATLAB. In a plain PowerShell window, `LoadLibrary` on
`ktvisa32.dll` succeeds. Do it again after loading MATLAB's `MSVCP140.dll` first
and it fails with 1114.

The fix is to replace the eight VC++ 14.x files in `bin\win64` with the System32
copies: `msvcp140`, `msvcp140_1`, `msvcp140_2`, `msvcp140_codecvt_ids`,
`vcruntime140`, `vcruntime140_1`, `concrt140` and `vccorlib140`. Back the
originals up first. This changes no MATLAB code and no licensing; the files are
Microsoft's, and Microsoft states that a program built against an older 14.x
runtime runs against a newer one.

It worked when `instrhwinfo('visa')` lists `keysight` and `visadevlist` shows the
instrument. A MATLAB repair or reinstall puts the old files back and returns the
fault.

## The current climbs through the run and the sweep aborts

A cell's current is flat until the knee and then falls. Current that rises while
the load resistance rises is not the cell; it is the illumination still coming
up, and it tracks the clock rather than the load. Run `20260828_163338` climbed
1.66× over fourteen minutes and eventually passed the ammeter's range, which
returns overflow, which is a NaN, and five in a row stop the run.

The ammeter follows its range now, so this costs a range change rather than the
run, and the end of a sweep reports how many it made. A run that keeps
re-ranging the ammeter is illumination moving.

`measureSettle` reports the same thing before the run starts. It watches the
slowest state settle, and if the reading is still moving at the end of the
window it says so and refuses to take a capacitance from it. A settling cell
puts its change at the front of the window and leaves the tail flat.

The fix is on the bench: let the source reach equilibrium before starting,
judged by the `SHORT` state current holding still. Nothing in software can
correct it, because a sweep measures each state at a different moment.

## The first read after opening a meter times out

Both meters talk continuously, so `visadev` can open partway through a reading.
The first `readline` then waits for a line ending that has already gone past, and
times out however long the timeout is. Every read after that is fine, which makes
it look intermittent when it is not.

`flush` the session immediately after opening it. `openMeter` does this. The
write terminator is not involved: `CR/LF` and `LF` behave identically, with and
without the flush.

## The 196 misbehaves for the first few exchanges of every session

One fault with many faces, and the faces were chased separately before the
cause was found: the first command of a session vanishing, `U0` answered with a
reading instead of the status word, `TRIGGER ERROR` on the display, and an
IDDCO latching into the error word with every command sent being valid, often
surfacing an exchange or two after whatever caused it.

The cause is MATLAB. `visadev` sends `*IDN?` to whatever it opens and offers no
way to turn that off (confirmed by MathWorks support, MATLAB Answers 2118301;
the suppression flag added in R2025a is on `visadevlist`, not `visadev`). The
196 predates SCPI and executes nothing without a trailing `X`, so the `*IDN?`
sits half-parsed in its input. The next real command is concatenated onto that
fragment, and the `X` it ends with executes the combined garbage: the command
is consumed, IDDCO latches for a string nobody knowingly sent, and both appear
late because nothing runs until that `X` arrives. Two writes in quick
succession into a fresh session make it worse, mangling into one string.

Separately, a power-cycled 196 wakes in `T0`, continuous on talk: being
addressed to talk is itself a trigger, so every read manufactures a fresh
reading and no query can be answered with anything else. No flush wins that
race.

`primeDdc` handles all of it at open: a bare `X` to execute and discard the
stranded fragment, one `T5` per attempt to leave trigger-on-talk, and the error
word read until clean, retrying the `T5` if the drain keeps collecting
readings. Because latched phantom bits can still surface later, setup
verification does not trust `U1` at all: `ddcVerifySetup` reads the `U0`
machine word back and compares the digits against what was sent, positions
mapped on this bench by toggling one setting at a time. The error word says
what the meter has been through; the machine word says what it is in.

The fragment also paints the front panel. `*IDN?` contains a `D`, the 196's
display-message command, so executing it leaves the tail of the query on the
display, where it reads `n7`, and a painted message stays until a bare `D`
restores the display. `primeDdc` sends that too. The `TRIG ERROR` the panel
flashes at the moment the fragment executes is the same event and clears when
the first real reading lands.

The 34401A is immune: `*IDN?` is exactly what it expects.

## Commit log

2026-08-26 PVLoad: programmable resistive load for PV I-V characterization
    Two MCP41HV51 digital potentiometers and three reed relays give 769 load
    states from 0.150 ohm to 470 kohm, driven over SPI from an Arduino Uno.
    MATLAB sweeps the load, sets illumination with a Thorlabs EDFA100P fiber
    amplifier, reads two bench multimeters over VISA, and writes CSV.
    Includes the Altium project, gerbers, hardware reference and design notes.
    [1N4148.PcbLib, 1N4148.SchLib, 2N3904BU.PcbLib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]
2026-08-26 Name the calibration arrays in the design notes
    The mapping moved from a CSV to two arrays in the script; the rationale
    still described it as a table.
2026-08-26 Drive the meters as Keithley 617 electrometers
    The bench meters are Keithley 617 programmable electrometers, not the
    Agilent 34401A the code assumed. The 617 predates SCPI, so the command
    layer is replaced rather than adjusted: device-dependent commands, U0 for
    identity, U1 for the error queue, and a trailing X to execute. Readings
    keep their prefix, so an overflowed point is now a fault instead of a
    full-scale number in the CSV.
    The electrometer removes two problems. Its ammeter is a feedback ammeter
    with under 3 mV of burden, so voltmeter placement no longer decides
    whether the Isc end carries signal, and its volts input is above
    200 TOhm, so the 470 kohm OPEN path is no longer a divider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
2026-08-26 Add board-only ramp and wiper bring-up modes
    The board is fabricated and the only instrument on the bench so far is a
    handheld meter across J1 and J3. Neither existing mode suited that: "board"
    walks eight states faster than a handheld updates, and "sweep" wants a cell,
    a laser and two electrometers.
    "ramp" is the same walk held long enough to read, printed before each state
    is applied so the console leads the meter instead of trailing it. "wiper"
    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
2026-08-26 Record K3 as not closing
    RUN = "k3" holds LOW and alternates the second pot between 0 and 255. With
    K3 closed that pot is shorted out and its code cannot reach the terminals,
    so the four holds have to read alike. They came back 308, 5270, 308, 5270:
    U2's entire ladder appears and disappears with its code, so K3 never
    operates and U2 sits in the path in LOW exactly as it does in FULL.
    That single fault accounts for both readings that made no sense alone. LOW
    and FULL agreed at every code because they contain the same elements, and
    the 242 ohm above SHORT is two wipers at about 121 ohm each rather than one
    wiper plus something unexplained.
    The mode is split out of "wiper" because it answers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
2026-08-26 Add a whole-board verify mode and measure R_WIPER
    A second board was assembled to the same design and needed checking as a
    unit rather than one element at a time. RUN = "verify" is seven holds that
    between them touch both chips over SPI, all three relays, both ladders and
    R1, with the pass conditions written as differences so the probe path does
    not enter any of them.
    Two of the seven drive the second pot while the board is in LOW. No planned
    state does that, because LOW always carries a zero second code, and it is
    the case that catches a K3 that never operates: with the relay shorting the
    pot out its code cannot reach the terminals, so the two holds must agree.
    Board 2 passes all seven. I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
2026-08-27 Add a printable bench card
    The connection details were spread across HARDWARE.md, the README and a
    handful of conversations, and none of it is any use at the bench on a
    laptop screen that is running the sweep. This is one printable sheet:
    header pinout, jack assignments, which cable each instrument needs and
    what it maps to in Part 1, the power sequence in both directions, and
    wiring diagrams for the three setups the bench actually goes through.
    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
2026-08-27 Keep the bench card to physical setup only
    The card is printed and used at the bench, next to a laptop that is
    already showing the script. Settings, mode names and file paths on it were
    duplicating what is on screen anyway, and pushing the wiring off the page.
    It now carries only what cannot be read off the screen: pinouts, jack
    assignments, which cable each instrument takes, what has to be set on the
    front panel of the instrument itself, the power sequence and the wiring.
    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
2026-08-27 Cut the bench card to one page
    Seven pages of it never left the printer. The diagrams were the worst of
    it: they took most of the space and still did not answer the one question
    that matters at the bench, which is how you physically put a box meter
    into the circuit. Words do that better. The ammeter goes inside the wire
    and the voltmeter goes across the cell, and saying so in two lines each
    beats a drawing nobody can trace.
    The power sequence is back to ten numbered steps with nothing beside them.
    The interlock is explained rather than named: it is a safety cutout meant
    for a door switch, and the shorting plug goes in it.
    The header table lost its function column and now just names the net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
2026-08-27 Say what 24 V on means on the bench card
    The step meant the supply's output switch, with both leads already seated
    in J2 and J3, but read as though something had to be plugged in live.
2026-08-27 Say which end of each cable the power steps mean
    Both rails are switched without unplugging anything from the board: the
    supply leads stay in J2 and J3 and the header wires stay on the Arduino.
    The 24 V step is the supply's output switch and the 5 V step is the USB
    cable at the laptop end, which the list did not say.
2026-08-27 Make the bench card usable by someone who has not seen the kit
    Adds how to operate a 617 at all: the power switch, the zero check that
    makes it read zero until released, the function buttons, the front panel
    address program and the remote light. Adds the handheld sockets and dial
    positions. Both were assumed knowledge and neither is obvious.
    Drops the rules and table borders, and the explanations of why. It is an
    instruction sheet, so it says what to do and stops.
2026-08-27 Plain-English pass over the bench card
    Instructions now start with the verb and name the actor. Vague phrasing
    that assumed the reader already knew the kit is gone: a socket that
    'makes the meter a plain piece of wire' now says it shorts J1 to J3, and
    the interlock is a safety cutout for a door switch rather than something
    the laser dies from.
    One term per thing throughout: bench supply, amps meter, volts meter,
    handheld meter, laptop.
2026-08-27 Put separator rules back on the bench card
    A light rule under each heading and a divider between the two columns.
    The pin table stays borderless; the rules that were removed were the
    ones boxing every cell in, not these.
2026-08-27 Write down the diagnostics and what the two ladders really buy
    Everything learned by probing the boards was in commit messages and
    nowhere a person would look. docs/TROUBLESHOOTING.md now carries it: which
    diagnostic mode answers which question, what each hold of "verify" proves,
    how to localise a relay drive with a voltmeter, and the four failure modes
    that present as something else. A missing 24 V rail reads as series
    resistance, and a relay that never closes reads as a component with no
    resistance; both cost time here before they were recognised.
    DECISIONS gains the part of the two-ladder argument that was missing. The
    second ladder does not halve the step. Its points land beside existin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
2026-08-27 List the ohms sweep alongside the other diagnostics
    TROUBLESHOOTING.md and CLAUDE.md were written before that mode existed and
    described the board-only diagnostics as four. The mode belongs in the same
    table: it answers what "ramp" answers, with a meter reading each state
    instead of a person copying numbers off a handheld, and it carries the same
    wiring offset that makes differences the thing to read.
2026-08-27 Support the Keithley 196 alongside the 617
    The bench has one 196 system DMM rather than a pair of 617 electrometers,
    and both speak the same device-dependent language, so the difference is a
    table rather than a driver. DMM_MODEL selects one of two profiles holding
    the function letters, the range lists, the setup string and the conversion
    time; everything below reads the profile instead of naming a 617.
    Two of the differences are structural. Amps is F3 on the 196, because F1
    and F2 are the AC functions an electrometer does not have, and a run that
    sent F1 would have measured AC volts and called it current. Zero check is
    an electrometer facility, so the C1/Z1/C0 sequence is skipped rather tha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
2026-08-27 Cut the illumination control and the 617, verify the 196
    Three changes that all fall out of what is actually on the bench: a
    Keithley 196, an Agilent 34401A, and a lamp with a knob on it.
    The lamp is set by hand now. The Thorlabs EDFA100P driver, the
    current-to-power calibration arrays, the level planning, the RUN "edfa"
    mode, the warm-up and the per-level CSV are all gone; one run of "sweep"
    is one curve at whatever light the bench is under, and a family of curves
    is several runs told apart by RUN_TAG. That trade is worth writing down
    rather than just making. A run is no longer self-describing, and a mis-set
    lamp is an operator error the software cannot catch. Against that, the only
    Class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
2026-08-28 Close the meters that did open when one of them does not
    connectMeters opened the voltmeter, then the ammeter, then identified each
    in turn, and the caller's cleanup guard was built from the struct it
    returned. A meter that opened and then failed to identify therefore had no
    guard over it at all, and its VISA session was left to whenever MATLAB got
    around to collecting the handle. The next run reopens an address the last
    one may still hold, which presents as a timeout on the first read rather
    than as anything to do with the instrument.
    RUN "ohms" called openMeter with the pre-profile signature, passing cfg and
    a DMM_R_ADDRESS field that no longer exists, and closed the result with
    delete on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
2026-08-28 Guard the board while the meters come up
    runSweepAll opened the board, then the meters, and runExperiment builds the
    cleanup guard from both. A meter that would not open therefore left the
    board energised with nothing watching it. The open is guarded now, and the
    ramp's note about wiper resistance still quoted the datasheet's 200 ohm
    maximum, which R_WIPER stopped being when board 2 measured 155.
2026-08-28 Set RUN to sweep for a run on a cell
    Also corrects the meter summary at the top: the 196's amps ranges start at
    300 uA, table 3-9, not the 3 mA an earlier inference put there.
2026-08-28 Stop trusting the 196 error word near a session open
    Every session-open fault of the last two days is one fault. visadev sends
    *IDN? to whatever it opens and offers no way not to (MathWorks support,
    MATLAB Answers 2118301). The 196 executes nothing without a trailing X,
    so the query sits half-parsed in its input, the next real command lands
    on top of it, and the X that command ends with executes the combination.
    That is the first command that vanished, the IDDCO latched with every
    command sent being valid, TRIGGER ERROR on the display, and all of it
    surfacing an exchange late. A power-cycled meter stacks T0 on top:
    trigger on talk, so every read manufactures a reading and U0 cannot be
    answer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
2026-08-28 Draw the curve and its numbers at the end of a sweep
    The sweep wrote a CSV and stopped there, which left the one mode the
    board exists for as the only one with nothing to look at afterwards.
    RUN "ohms" has had a figure since it was written.
    summariseCurve takes Isc and Voc from the SHORT and OPEN states rather
    than from the extremes of the sweep, since that is what those states
    are, and falls back to the extremes with a note when a partial run is
    missing one. Magnitudes throughout: which sign the leads produce is a
    wiring choice, and the first quadrant is what gets published. The CSV
    keeps what the meters reported.
    The figure follows the convention: one panel, voltage across, current
    on th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
2026-08-28 Hold every state 100 ms for the cell's junction capacitance
    C_LOAD covers the leads and the meter input and nothing else, so the
    cell's own capacitance had no term with a number in it. Unmeasured on
    this receiver, so 100 ms is a deliberate over-estimate: it lands on
    every state and takes the sweep from 5.5 minutes to 7.4, which is
    cheap next to a curve whose knee moves with sweep speed.
2026-08-28 Size the run for the cell that is actually on the bench
    ISC_FULL was 16 mA and VOC_FULL 9 V, neither of them measured. The first
    sweep on a cell, run 20260828_145929 at 0.42 A of laser drive, returned
    64.8 uA and an OPEN state at 3.384 V. Those are now the numbers, and the
    main thing they buy is the ammeter range: the 196 was on 30 mA with the
    cell in the bottom 0.2 percent of it, and 100 uA puts it on 300 uA.
    Two things that run showed cannot be fixed by a constant, so they are
    reported instead of hidden. The OPEN state drew 10.9 percent of Isc
    through R1, which makes its voltage a floor under Voc rather than Voc,
    and fill factor inherits that. The largest power in the sweep was the
    last s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
2026-08-28 Measure the cell instead of being told about it
    ISC_FULL and VOC_FULL existed for one reason: the meters are put on a
    fixed range before the first state and something has to size them. That
    number was an operator's estimate at an illumination the software cannot
    see, and when it was wrong by 250x, as it was on the first sweep with a
    cell, the ammeter spent the run in the bottom 0.2 percent of its range.
    The sweep already visits the two states that answer the question. OPEN
    is the largest voltage of the run and SHORT is the largest current, and
    every other state is one of those two with resistance added, so two
    readings on autorange bound the whole sweep. probeRanges takes them
    before the ru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
2026-08-28 Say whether the knee is reachable before sweeping for it
    The probe measures Isc and Voc, so the resistance that lands on the
    maximum power point is a division away: Vmp over Imp, taking the usual
    0.8 of Voc and 0.9 of Isc. Rough, and rough is enough to answer the only
    question worth asking first, which is whether that resistance is inside
    a ladder spanning 155 ohm to 10.3 kohm.
    The cell on the bench wants 46 kohm and the run that found that out took
    eleven minutes to not reach it. Now it says so in the first five seconds
    and names what would fix it: 292 uA of short-circuit current, 4.5x the
    illumination, brings the knee to the top of the ladder. A cell too
    bright warns the other way, since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
2026-08-28 Stop the code from bending the curve it measures
    Three faults on my side of the wire, all of them costing accuracy at
    every point rather than failing outright.
    The 196 was set to S2, 5.5 digits and 24 ms, on a bench where the 34401A
    next to it takes 393 ms and the two conversions overlap. The 196 has
    been finishing in a fifth of that window and waiting. S3 is 6.5 digits
    and 106 ms, still inside the window, so the point costs exactly what it
    cost before and the ammeter resolves 1 nA instead of 10.
    The cell's capacitance was a flat 100 ms, which is the wrong shape.
    Settling is RC, so the error grows with resistance, and resistance is
    what the sweep is ordered by: guessing low does not scatte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
2026-08-28 Put the voltmeter on the right range at every point
    The ladder of a dim cell crosses three decades. The first cell run spent
    768 states between 0.6 mV and 0.68 V with the meter fixed on one range,
    and on a 34401A the error there is not one number: 0.0035% of reading
    plus 0.0005% of range means that at 10 mV on the 10 V range the floor is
    50 uV against 0.35 uV of gain error. Nearly all of it was range.
    The voltmeter now follows the reading. It widens at 90% of range or on an
    overflow, and narrows once the reading drops under 8%, straight to the
    range that fits rather than one step at a time, because the state after
    SHORT falls from volts to millivolts in one move. The gap between those
    two t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
2026-08-28 Put back three functions an edit had deleted
    probeState, probeRead and reportKnee were removed by the edit that
    replaced the two-range voltmeter with the adaptive one, and their callers
    were not. Nothing static caught it: checkcode does not resolve calls
    between local functions, and the harnesses that would have hit it were
    stale copies carrying the old definitions, which is my fault for running
    them without regenerating.
    A sweep would have opened the board, opened both meters, and died at the
    first line of the probe with an undefined function. Found by running the
    whole thing against a simulated board and two simulated meters answering
    from a diode curve, which is now the check that matter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
2026-08-28 Let the ammeter follow the light instead of aborting on it
    Run 20260828_163338, at 0.45 A of laser drive, climbed from 125 uA to
    197 uA over fourteen minutes while the load resistance was increasing,
    which is the opposite of what a cell does along its own curve. That is
    the illumination still coming up. It ran off the top of the 300 uA range
    the probe had pinned, returned six overflows, and the sweep aborted at
    state 541 with 512 rows on disk.
    Two things of mine made that worse than it had to be.
    The ammeter was fixed on the argument that current is flat across a
    sweep. True of the cell, not of the bench. It now follows its range the
    way the voltmeter already did, widening on overflow and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
2026-08-28 Spend sweep states where the curve bends
    A coarse pass measures the whole range first, and states are then added
    between measured neighbours wherever the curve bends, a gap is wide
    enough to hide the knee, or the maximum power point still has room to
    resolve. Every decision comes from the measured voltages and currents;
    the resistance model keeps to ordering the states. A cell run this way
    took 55 states instead of 769 and landed the same Pmax the full ladder
    would have.
    The refinement rounds revisit low resistances after high ones, so the
    ammeter now widens range for as many steps as the reading needs rather
    than one. The run also reads SHORT again after the last point and
    reports how far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
2026-08-28 Hold refinement above the light's own noise floor
    The points run in order of increasing load, so on one curve the current
    can only fall and the voltage can only rise; every step the wrong way
    is the illumination having moved between readings, and the mean size of
    those steps measures the wobble. Both refinement thresholds now sit on
    top of that floor. A source that will not hold still widens what counts
    as a bend instead of feeding an endless split of segments whose shape
    is noise: the 0.55 A run sat at the laser's threshold, wobbled about
    ten percent, and spent a hundred states chasing it. A clean curve has
    no wrong-way steps and a zero floor, leaving both settings untouched.
    A fill factor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
2026-08-31 Delete the paths the bench no longer takes
    RUN "k3" answered whether K3 closes with four holds. "verify" answers the
    same question with its last two, at the same states, so the mode was a
    subset of one that already runs on anything freshly built. Board 1's
    recorded fault now cites the test rather than the deleted mode.
    INCLUDE_SHORT, INCLUDE_OPEN and VERIFY_WIPER read as choices and had one
    safe value each. Clearing either endpoint flag deletes Isc or Voc from the
    data, and clearing the readback sweeps blind past a bad chip select. All
    three are unconditional now.
    The fixed sweep has not run since refinement landed, and nothing can reach
    it: it needs a board and two meters, so no harness c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
2026-08-31 Cut the comments back to what carries information
    The prose had grown to a third of the file, much of it restating the code
    beneath it or retelling decisions that already live in docs/. What remains
    is the part a reader cannot recover from the source: the relay ordering
    rules, the instrument quirks that make primeDdc and ddcAsk look arbitrary,
    the manual sections a constant came from, and the bench failures that put
    a guard where it is.
    No executable line changed. Stripping every comment from both files leaves
    them byte-identical to their previous versions.
